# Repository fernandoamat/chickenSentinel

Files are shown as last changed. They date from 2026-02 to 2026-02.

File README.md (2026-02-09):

# ChickenSentinel

An autonomous chicken deterrent system using computer vision and a water spray turret. The system detects birds and other animals using a DepthAI OAK-D stereo camera with YOLOv6 object detection, then tracks and sprays targets that venture outside designated "safe zones" (grass areas).

This project was develop in partnership with Gemini 3.0 to refine the ideas and parts list and then with Claude Code to implement all the code. It is definitely a passion project but it is saving my lawn and patio from being invaded by my chickens.

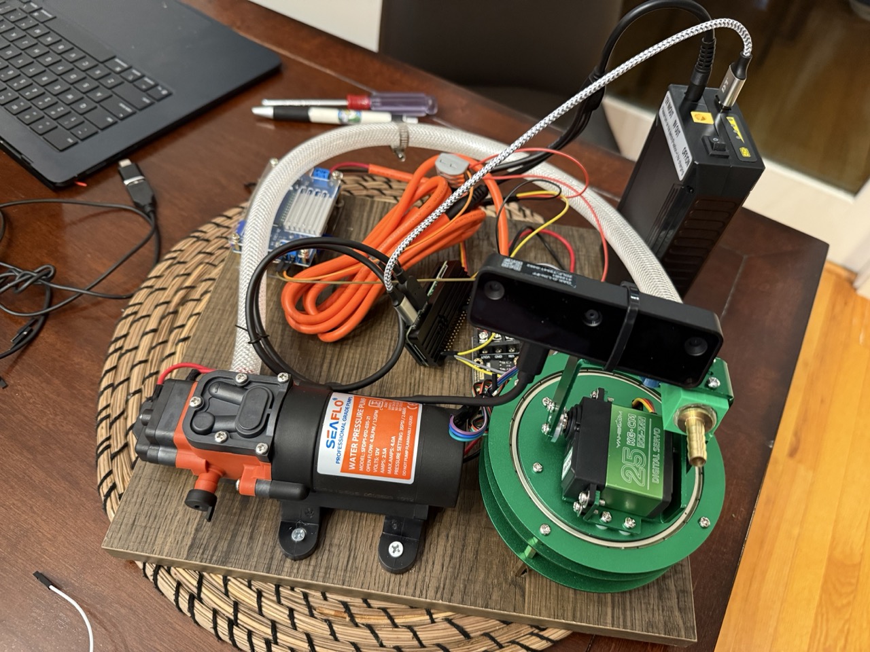
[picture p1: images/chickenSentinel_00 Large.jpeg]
chickenSentinel00
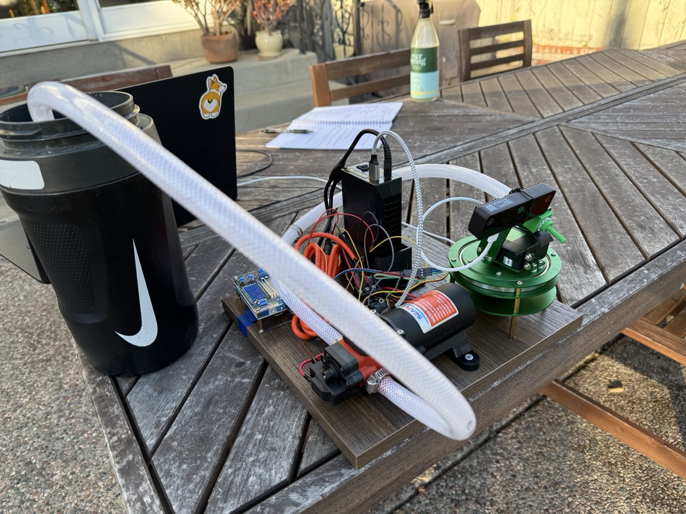
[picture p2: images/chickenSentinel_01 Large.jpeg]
chickenSentinel01

Pictures of how the final system looks like. It is totally portable in a 12x12 wood board. The battery can easily be removed to charge. It last ~6-8 hours as long as it is not shooting all the time. Right image shows final build with the pump connected to bucket with water.

[Video](https://github.com/user-attachments/assets/673e242a-7802-41d2-aea9-533b167c6f6e) demonstrating the system detecting and squirting water to a bottle (capturing footage with the chickens was hard). It much easier to debug with inanimate objects but the system works exactly the same with any other object (like chickens) that can be detected and tracked by the camera.

## System Block Diagram

```
       +-----------------------+
       |   TalentCell Battery  |
       |  (12V DC  &  5V USB)  |
       +---+---------------+---+
           |               |
           | 12V           | 5V USB
           v               v
    +-------------+   +-------------------------+
    |  Water Pump |   |  Raspberry Pi Zero 2 W  |
    |   (12V DC)  |   |      (Controller)       |
    +------+------+   +----+-------+--------+---+
           |               |       |        |
           |               | USB   | GPIO   | GPIO
           |               v       v        v
    +------+------+   +--------+  +----+  +--------+
    |   MOSFET    |<--| GPIO 17|  |Pan/|  | OAK-D  |
    |  (Switch)   |   +--------+  |Tilt|  | Lite   |
    +-------------+               |Svrs|  | Camera |
           ^                      +----+  +--------+
           |
      Common GND
```

## Software design
```
┌─────────────────────┐     USB      ┌─────────────────────────────────┐
│      OAK-D          │─────────────▶│     Raspberry Pi Zero 2W        │
│  Stereo Camera      │              │                                 │
│                     │              │  ┌─────────────────────────┐    │
│  - Color camera     │              │  │  auto_turret_control.py │    │
│  - Left/Right mono  │              │  │                         │    │
│  - VPU (runs YOLO)  │              │  │  State Machine:         │    │
│                     │              │  │  SCANNING → TRACKING    │    │
│  Outputs:           │              │  │  TRACKING → SHOOTING    │    │
│  - Detections       │              │  │  SHOOTING → COOLDOWN    │    │
│  - Spatial coords   │              │  └───────────┬─────────────┘    │
│  - RGB frames       │              │              │                  │
└─────────────────────┘              │              ▼                  │
                                     │  ┌─────────────────────────┐    │
                                     │  │  Hardware Control       │    │
                                     │  │  - Pan servo (GPIO 12)  │    │
                                     │  │  - Tilt servo (GPIO 13) │    │
                                     │  │  - Water pump (GPIO 17) │    │
                                     │  └─────────────────────────┘    │
                                     └─────────────────────────────────┘
```

**Key insight:** YOLO inference runs on the OAK-D's neural accelerator (VPU), not on the Raspberry Pi. The Pi only receives detection results, making this efficient enough for the resource-constrained Zero 2W.

## Hardware Requirements

- **Camera:** OAK-D or OAK-D Lite (DepthAI-compatible stereo camera)
  - Color camera (CAM_A)
  - Left/Right mono cameras (CAM_B, CAM_C) for stereo depth
- **Controller:** Raspberry Pi Zero 2W (or any Pi with GPIO)
- **Actuators:**
  - 2x servo motors (pan/tilt) - standard 50Hz PWM servos
  - Water pump with relay/MOSFET control
- **Power:** Appropriate power supply for servos and pump

### GPIO Pin Assignments

| Component | GPIO Pin | PWM Channel |
|---|---|---|
| Pan Servo | 12 | Channel 0 |
| Tilt Servo | 13 | Channel 1 |
| Water Pump | 17 | Digital Out |

## 🛠️ Parts lists
Total cost in December 2025 for the entire project was around $350.

| Component | Description | Model / Notes | Buy Link |
| :--- | :--- | :--- | :--- |
| **Controller** | Single Board Computer | **Raspberry Pi Zero 2 W**<br>The brain of the sentinel. | [Buy from Raspberry Pi](https://www.raspberrypi.com/products/raspberry-pi-zero-2-w/) |
| **Camera** | AI Camera | **Luxonis OAK-D Lite**<br>Planned upgrade for person/animal detection. | [Buy from Luxonis](https://shop.luxonis.com/products/oak-d-lite-1) |
| **Turret Mechanism** | Pan/Tilt Kit | **Pan/Tilt Bracket + 2x Servos**<br>Generic kit for aiming. | [Amazon](https://www.amazon.com/Yahboom-Pan-Tilt-Electric-Platform-Accessories/dp/B0BRXVFCKX) |
| **Water Cannon** | Pump | **12V DC Submersible Pump**<br>Connected to GPIO 17 via MOSFET. | [Amazon](https://www.amazon.com/dp/B00DLKT4OO) |
| **Pump Control** | Switch | **MOSFET Module DF-DFR0457**<br>Allows the 3.3V Pi to switch on/off the 12V pump. | [Buy from TME](https://www.tme.com/us/en-us/details/df-dfr0457/others-power-supply-modules/dfrobot/dfr0457/) |
| **Power Supply** | Battery | **TalentCell Rechargeable 12V/5V**<br>Powers both the Pi (via 5V USB) and Pump (via 12V DC). | [Amazon](https://www.amazon.com/dp/B01337QXMA) |
| **DC Buck Converter** | Converter | **Adjustable Power Supply**<br>Lowers the DC current of the battery from 12V to 7.6V for the servos. | [Amazon](https://www.amazon.com/dp/B078Q1624B) |
| **Power Splitter** | Cable Splitter | **Y-Splitter Cable**<br>Power splitter for both servos. | [Amazon](https://www.amazon.com/dp/B0FCD32RBB) |
| **USB Power Cable** | Power Cable | **USB to Barrel Jack**<br>Powers Raspberry Pi from battery. | [Amazon](https://www.amazon.com/dp/B0FS651N2G) |
| **DC Power Cables** | Power Cables | **DC Barrel Cables**<br>Connects splitter to DC converter. | [Amazon](https://www.amazon.com/dp/B0CRB1QP71) |
| **Vinyl Tubing** | Water Tubing | **Flexible Vinyl Tube**<br>Carries water from pump to nozzle. | [Amazon](https://www.amazon.com/dp/B07MTYMW13) |
| **USB-C Cable** | Data Cable | **USB-C to USB-A**<br>Connects OAK-D camera to Raspberry Pi. | [Amazon](https://www.amazon.com/dp/B0D97GS238) |
| **Jumper Wires** | Wiring | **Dupont Jumper Wires**<br>Pin wires to connect GPIO components. | [Amazon](https://www.amazon.com/dp/B01EV70C78) |

## File Structure

```
chickenSentinel/
├── chicken_tracker.py          # Desktop visualization with YOLO + depth
├── raspberrypi/
│   ├── auto_turret_control.py  # Autonomous turret controller
│   └── manual_turret_control.py # Manual servo/pump testing
├── notebooks/
│   └── debug_green_mask.ipynb  # Green zone detection debugging
├── openscad/                   # 3D printable parts
│   ├── nozzleAttachmentServo.scad
│   └── batteryBase.scad
├── pyproject.toml              # Project dependencies
├── CLAUDE.md                   # AI assistant instructions
└── README.md                   # This file
```

## Installation

```bash
# Clone the repository
git clone https://github.com/yourusername/chickenSentinel.git
cd chickenSentinel

# Install dependencies (uses uv package manager)
uv sync

# For Raspberry Pi, also install hardware PWM support:
pip install rpi-hardware-pwm gpiozero
```

## Usage

### Automated Turret (Production)

Run on the Raspberry Pi connected to the OAK-D camera:

```bash
uv run python raspberrypi/auto_turret_control.py
```

Monitor via SSH - the script outputs timestamped logs:
```
14:32:15 [INFO] Pipeline started. Entering main loop...
14:32:18 [INFO] Target acquired: bird conf=0.87 z=2450mm
14:32:19 [INFO] Centered! X=32mm. Shooting...
14:32:22 [INFO] Shot complete. Cooldown...
14:32:23 [INFO] Resuming tracking
14:32:26 [INFO] Target lost for 5.0s. Scanning...
14:32:45 [INFO] Status: state=SCANNING, pan=-15.0, tilt=0.0, detections=3
```

### Manual Turret Control (Testing)

For manual testing of servos and pump:

```bash
uv run python raspberrypi/manual_turret_control.py
```

Controls:
- Arrow keys: Pan/Tilt
- `s`: Shoot (3 seconds)
- `q`: Quit

### Desktop Visualization (Development)

For development/debugging with video display:

```bash
uv run python chicken_tracker.py
```

## Auto Turret Control - Detailed Documentation

### State Machine

The turret operates as a finite state machine with 4 states:

```
                    ┌──────────────────────────────────────┐
                    │                                      │
                    ▼                                      │
┌──────────┐   detection    ┌──────────┐   centered    ┌──────────┐
│ SCANNING │──────────────▶│ TRACKING │──────────────▶│ SHOOTING │
└──────────┘               └──────────┘               └──────────┘
     ▲                          │                          │
     │                          │                          │
     │      target lost         │                          │
     │      for 5 seconds       │                          │
     │◀─────────────────────────┤                          │
     │                                                     │
     │                     ┌──────────┐                    │
     │    cooldown done    │ COOLDOWN │◀───────────────────┘
     │◀────────────────────┴──────────┘    shoot done
```

| State | Description | Transitions |
|---|---|---|
| `SCANNING` | No target detected. Pans back and forth within `SCAN_RANGE`. Tilt at neutral (0°). | → TRACKING (when valid target detected) |
| `TRACKING` | Target acquired. Adjusts pan/tilt to center target using trigonometry-based control. | → SHOOTING (when centered), → SCANNING (target lost for 5s) |
| `SHOOTING` | Pump activated. Holds position for `SHOOT_DURATION`. | → COOLDOWN (when done) |
| `COOLDOWN` | Pause after shooting (`COOLDOWN_DURATION`) or after full scan with no targets (`IDLE_COOLDOWN_DURATION`). | → TRACKING (if target visible), → SCANNING (if no target) |

### Configuration Constants

All tunable parameters are at the top of `raspberrypi/auto_turret_control.py`:

#### Detection Settings

| Constant | Default | Description |
|---|---|---|
| `ALLOWED_CLASSES` | `{'bird', 'horse', 'sheep', 'cow', 'bear', 'bottle'}` | YOLO classes to target |
| `FPS` | 15 | Camera frame rate (reduced for efficiency) |

#### Timing

| Constant | Default | Description |
|---|---|---|
| `SHOOT_DURATION` | 3.0 | Seconds to spray water |
| `COOLDOWN_DURATION` | 10.0 | Seconds pause after shooting |
| `IDLE_COOLDOWN_DURATION` | 30.0 | Seconds to idle after full scan with no detections |
| `GREEN_MASK_INTERVAL` | 10.0 | Seconds between green mask updates |

#### Scanning Mode

| Constant | Default | Description |
|---|---|---|
| `SCAN_RANGE` | `(-40, 60)` | Pan angle range in degrees |
| `SCAN_STEP` | 5 | Degrees per scan movement |
| `SCAN_DELAY` | 0.5 | Seconds between scan steps |
| `SCANNING_TILT_ANGLE` | 25.0 | Tilt angle during scanning (degrees) |

#### Tracking Control

| Constant | Default | Description |
|---|---|---|
| `CENTERING_THRESHOLD` | 50 | mm X-offset to consider "centered" |
| `TRACKING_DELAY` | 0.5 | Seconds to wait after servo command before next measurement |
| `TARGET_DETECTION_CONFIDENCE_THRESHOLD` | 0.5 | Minimum confidence to consider a detection valid |
| `TARGET_LOST_TIMEOUT` | 5.0 | Seconds before scanning after losing target |
| `MAX_PAN_RATE` | 2.0 | Maximum degrees per update cycle (smooth movement) |

#### Monitoring

| Constant | Default | Description |
|---|---|---|
| `STATUS_LOG_INTERVAL` | 30.0 | Seconds between periodic status logs |

### Key Functions

#### `calculate_target_y(z_mm: float) -> float`

**Location:** `auto_turret_control.py:102-118`

Calculates the target Y coordinate (in mm) that the turret should aim at based on target distance. The tilt servo uses proportional control to minimize the offset between the detection's actual Y coordinate and this target value. **This needs calibration** based on your turret mounting position and water nozzle trajectory.

Current implementation uses a linear regression formula:
```python
def calculate_target_y(z_mm: float) -> float:
    # y = 0.3654 * z - 282.318
    return (0.3654 * z_mm) - 282.318
```

Both pan and tilt use trigonometry-based angle calculations:
- **Pan**: Uses `atan2(x_offset, z_depth)` to calculate the exact angular offset to center the target horizontally
- **Tilt**: Uses `atan2(y_offset, z_depth)` where y_offset is the difference between actual Y and the calibrated target Y

#### `GreenZoneDetector`

**Location:** `auto_turret_control.py:126-174`

Detects grass/green areas using simple RGB thresholding. Targets standing on grass are considered "safe" and won't be sprayed.

- Updates mask every `GREEN_MASK_INTERVAL` seconds
- A pixel is "green" if: `G > R + threshold` AND `G > B + threshold`

#### `is_valid_spatial_coordinates(detection) -> bool`

**Location:** `auto_turret_control.py:182-199`

Validates that a detection has usable 3D coordinates:
- Checks for NaN values in x, y, z coordinates
- Ensures depth (z) is positive

#### `select_best_detection()`

**Location:** `auto_turret_control.py:202-244`

Selects the highest-confidence detection that:
1. Is in `ALLOWED_CLASSES`
2. Has valid spatial coordinates (not NaN, positive depth)
3. Is within 4000mm depth range
4. During scanning: has Y coordinate above -600mm

### Safety Features

The system will only shoot when ALL conditions are met:
1. Target class is in `ALLOWED_CLASSES`
2. Target has valid spatial coordinates (not NaN, positive depth)
3. Target depth is less than 4000mm
4. Target is centered (X offset < `CENTERING_THRESHOLD`)
5. Not in cooldown period

**Note:** Green zone detection (grass area filtering) is implemented but currently disabled in the code. A physical boundary was found to be more reliable than tuning the green detector.

### Robustness Features

The code includes several robustness improvements for reliable operation:

- **Non-blocking detection queue**: Uses `tryGet()` to prevent hanging if camera disconnects
- **Graceful degradation**: State machine continues running even without camera data
- **Hardware cleanup guarantee**: `finally` block ensures pump/servos are stopped on any exit
- **Exception handling**: All hardware operations wrapped in try/except with logging
- **Periodic status logging**: Logs state, angles, and detection count every 30 seconds
- **Pan rate limiting**: Prevents jerky servo movements with `MAX_PAN_RATE`
- **Tilt reset on scan**: Returns tilt to neutral when entering scanning mode

## Calibration Guide

### 1. Tracking Rate Tuning

The turret uses trigonometry-based angle calculations with `math.atan2()` to determine the exact angular offset to the target. The `MAX_PAN_RATE` constant limits how fast the servos can move per update cycle for smooth tracking.

If tracking is too slow, increase `MAX_PAN_RATE`. If the servos oscillate or overshoot, decrease it.

```python
MAX_PAN_RATE = 2.0  # Maximum degrees per update cycle
```

### 2. Target Y Calibration

The `calculate_target_y()` function defines what Y coordinate (in mm) the turret should aim at for a given depth. To calibrate:

1. Place a target at known distances (e.g., 1m, 2m, 3m, 4m, 5m)
2. For each distance, note the Y coordinate reported when the water hits the target
3. Fit a linear regression to your data points (Z vs Y)
4. Update the formula in `calculate_target_y()`

### 3. Green Zone Threshold

If the green detection is too sensitive (missing grass) or not sensitive enough (detecting non-grass as grass), adjust:

```python
# In GreenZoneDetector.__init__()
self.threshold = 0  # Increase if false positives, decrease if missing grass
```

## Dependencies

- `depthai>=3.2.1` - DepthAI camera SDK
- `opencv-python>=4.11.0.86` - Computer vision
- `numpy>=2.3.5` - Numerical processing
- `blobconverter>=1.4.3` - Neural network model conversion
- `matplotlib>=3.10.8` - Plotting (for debugging notebooks)
- `gpiozero>=2.0.1` - GPIO control (Raspberry Pi)
- `rpi-hardware-pwm` - Hardware PWM for servos (Raspberry Pi)

## 3D Printed Parts

The `openscad/` directory contains STL files for custom mounting hardware. All parts were designed in OpenSCAD and can be modified if needed.

| Part | File | Description |
| :--- | :--- | :--- |
| **Nozzle Adapter** | `nozzleAttachmentServo.stl` | Mounts the brass hose fitting to the pan/tilt bracket. Uses M3 screws. |
| **Battery Holder** | `batteryBase.stl` | Sleeve for the TalentCell battery with screw-down mounting flanges. |
| **Hose Connector** | `M0110_double-ended-barbed-hose-connector.stl` | Barbed connector for vinyl tubing. Can also be purchased online. |

**Print settings:** PLA or PETG, 0.2mm layer height, 20% infill. No supports needed.

## License

MIT License

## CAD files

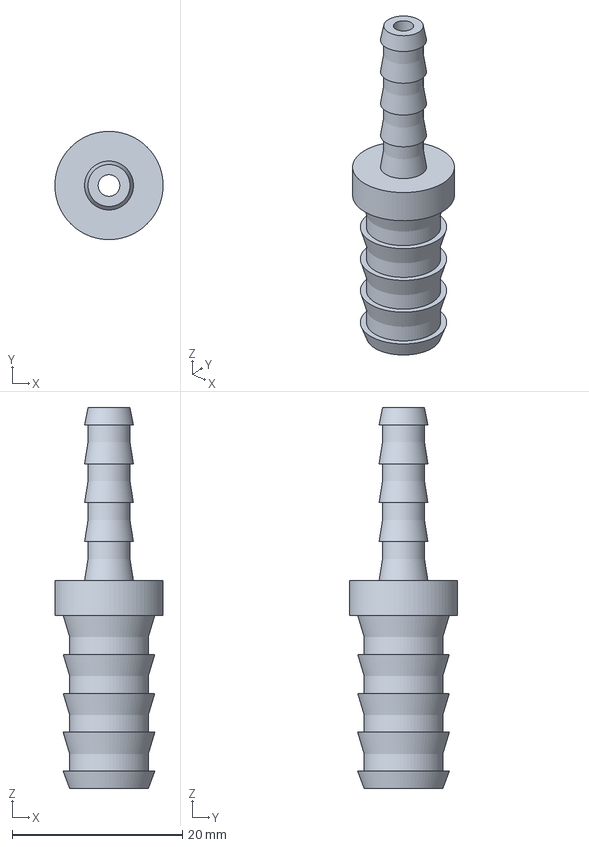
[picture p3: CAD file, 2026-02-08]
openscad/M0110_double-ended-barbed-hose-connector.3mf
12.7 x 12.7 x 44.7 mm

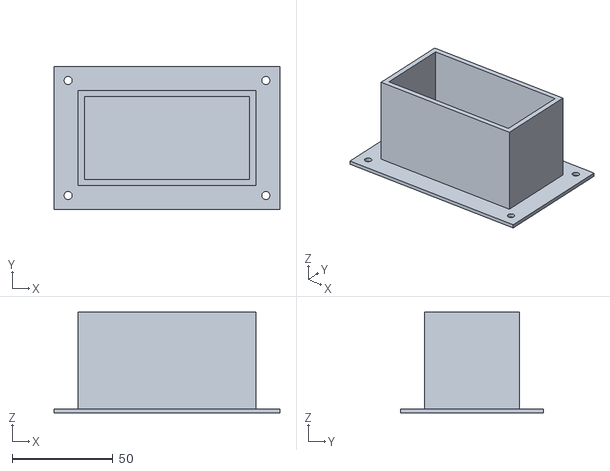
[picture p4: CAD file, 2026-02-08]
openscad/batteryBase.stl
112.0 x 71.0 x 50.0

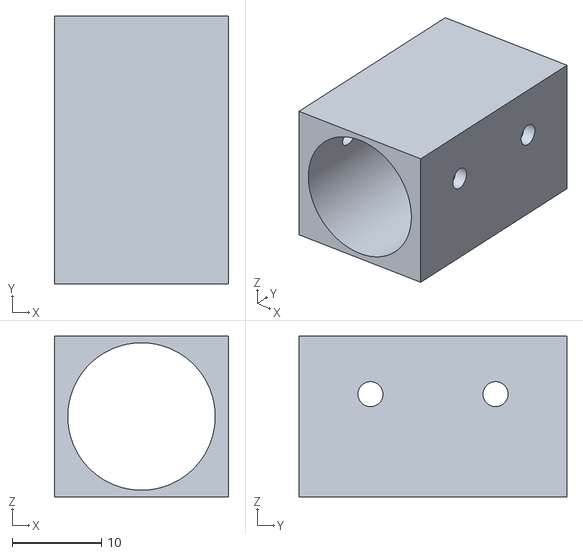
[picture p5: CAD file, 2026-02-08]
openscad/nozzleAttachmentServo.stl
19.5 x 30.0 x 18.0

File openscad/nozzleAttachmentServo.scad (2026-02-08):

// --- MEASURE YOUR BRASS FITTING ---
nozzle_barrel_dia = 16.5;    // Diameter of the round threaded part

// --- MOUNTING SETTINGS ---
// 2.8mm is tight for M3, allowing the screw to cut its own threads into the plastic.
// If it's too hard to screw in, drill it out slightly to 3.0mm.
mount_screw_dia = 2.8;     
hole_spacing = 14;         // Distance between the two mounting holes
whole_offset = 2.5;      // Offset to the wall

$fn=100;

difference() {
    // 1. The Main Block
    cube([nozzle_barrel_dia + 3, 30, nozzle_barrel_dia + 1.5], center=true);


    // 3. The Barrel Exit (Where water comes out)
    rotate([90, 0, 0])
        translate([0, 0, -10])
            cylinder(h=20, d=nozzle_barrel_dia, center=true);
            
    // 4. The Hose Entrance (Rear)
    rotate([90, 0, 0])
        translate([0, 0, 10])
            cylinder(h=30, d=nozzle_barrel_dia, center=true);

    // 5. Fixed Mounting Holes (13mm spacing)
    // Top Hole
    translate([0, hole_spacing/2, whole_offset]) 
        rotate([0, 90, 0]) 
            cylinder(h=30, d=mount_screw_dia, center=true);
            
    // Bottom Hole
    translate([0, -hole_spacing/2, whole_offset]) 
        rotate([0, 90, 0]) 
            cylinder(h=30, d=mount_screw_dia, center=true);
}

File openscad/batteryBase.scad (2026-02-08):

// --- Parameters ---

// Inner dimensions of the sleeve (Battery size + tolerance)
// I have set these to match the standard YB1208300-USB (approx 80mm x 39mm)
inner_width = 82;  // Long side (approx 8cm + clearance)
inner_depth = 41;  // Short side (approx 4cm + clearance)

// Height of the sleeve walls
total_height = 50;

// Thickness of the walls and base floor
wall_thickness = 3;
floor_thickness = 2; 

// Width of the mounting tabs (ears) for the screws
tab_width = 12;

// Screw hole diameter (standard M3 or wood screw is ~3-4mm)
screw_hole_diameter = 4;

// Smoothness of circles
$fn = 60;

// --- Main Render ---

difference() {
    // 1. The main solid body (Base + Walls)
    union() {
        // The Sleeve Walls (Outer Block)
        translate([0, 0, total_height/2])
            cube([inner_width + 2*wall_thickness, inner_depth + 2*wall_thickness, total_height], center=true);
        
        // The Mounting Flanges (Base ears at corners)
        // We create a larger flat plate at the bottom for the screws
        translate([0, 0, floor_thickness/2])
            cube([inner_width + 2*wall_thickness + 2*tab_width, inner_depth + 2*wall_thickness + 2*tab_width, floor_thickness], center=true);
    }

    // 2. Subtract the "Hole" for the battery
    // We shift it up by 'floor_thickness' so the battery sits on a floor, not the wood.
    translate([0, 0, floor_thickness + (total_height/2)])
        cube([inner_width, inner_depth, total_height + 1], center=true);

    // 3. Subtract the Screw Holes (4 Corners)
    // We calculate the positions based on the total size
    
    // X and Y positions for the holes
    hole_x = (inner_width/2) + wall_thickness + (tab_width/2) - 1; 
    hole_y = (inner_depth/2) + wall_thickness + (tab_width/2) - 1;

    // Front-Right
    translate([hole_x, hole_y, -1])
        cylinder(h = total_height + 2, d = screw_hole_diameter);
    
    // Front-Left
    translate([-hole_x, hole_y, -1])
        cylinder(h = total_height + 2, d = screw_hole_diameter);
        
    // Back-Right
    translate([hole_x, -hole_y, -1])
        cylinder(h = total_height + 2, d = screw_hole_diameter);
        
    // Back-Left
    translate([-hole_x, -hole_y, -1])
        cylinder(h = total_height + 2, d = screw_hole_diameter);
}

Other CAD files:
openscad/M0110_double-ended-barbed-hose-connector.stl

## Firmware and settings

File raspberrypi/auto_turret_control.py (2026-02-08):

"""
Automated turret control for Raspberry Pi Zero 2W.

Combines DepthAI YOLOv6 detection with servo control for autonomous
chicken deterrent. YOLO inference runs on OAK-D's VPU (neural accelerator),
so the RPi only handles lightweight control logic.

Usage:
    uv run python raspberrypi/auto_turret_control.py
"""

import logging
import math
import time
from enum import Enum

import depthai as dai
import numpy as np
from gpiozero import DigitalOutputDevice
from rpi_hardware_pwm import HardwarePWM

# =============================================================================
# CONFIGURATION - Adjust these constants as needed
# =============================================================================

# Detection settings
ALLOWED_CLASSES = {'bird', 'horse', 'sheep', 'cow', 'bear', 'bottle'}
FPS = 15  # Reduced from 30 for RPi Zero 2W efficiency

# Timing
SHOOT_DURATION = 3.0  # Seconds to spray water
COOLDOWN_DURATION = 10.0  # Seconds after shooting before resuming
IDLE_COOLDOWN_DURATION = 30.0  # Seconds to idle after full scan with no detections. Increase to preserve battery.
GREEN_MASK_INTERVAL = 10.0  # Seconds between green mask updates. Increase to reduce CPU load.

# Scanning mode
SCAN_RANGE = (-40, 60)  # Pan angle range (degrees)
SCAN_STEP = 5  # Degrees per scan movement
SCAN_DELAY = 0.5  # Seconds between scan steps
SCANNING_TILT_ANGLE = 25.0  # Tilt angle during scanning (degrees). Adjust to your mounting position.

# Tracking control
CENTERING_THRESHOLD = 50  # mm - X offset considered "centered"
TRACKING_DELAY = 0.5  # Seconds to wait after servo command before next measurement

# Targeting control
TARGET_DETECTION_CONFIDENCE_THRESHOLD = 0.5  # Minimum confidence to consider a detection valid. Increase to reduce false positives.

# Hardware pins
PUMP_PIN = 17
PAN_PWM_CHANNEL = 0  # GPIO 12
TILT_PWM_CHANNEL = 1  # GPIO 13

# Tracking behavior
TARGET_LOST_TIMEOUT = 5.0  # Seconds before scanning after losing target
MAX_PAN_RATE = 2.0  # Maximum degrees per update cycle for smooth movement. Critical for smooth tracking.

# Monitoring
STATUS_LOG_INTERVAL = 30.0  # Seconds between periodic status logs

# =============================================================================
# HARDWARE SETUP
# =============================================================================


def set_angle(pwm_device, angle: float, log) -> None:
    """
    Set servo angle.

    Args:
        pwm_device: HardwarePWM instance
        angle: Angle in degrees (-90 to +90)
    """
    # too much logging
    # log.info(f"Setting servo angle (pan or tilt) to {angle} degrees")
    angle = max(-90, min(90, angle))
    # Convert angle to duty cycle (Equation: 2.5 + (angle + 90) / 180 * 10)
    # Servo PWM: 2.5% = -90deg, 7.5% = 0deg, 12.5% = +90deg
    duty_cycle = 2.5 + (angle + 90) / 18.0
    pwm_device.change_duty_cycle(duty_cycle)


# =============================================================================
# STATE MACHINE
# =============================================================================


class TurretState(Enum):
    SCANNING = 1  # No detection, panning to search
    TRACKING = 2  # Detection found, centering on target
    SHOOTING = 3  # Centered and outside green zone, firing
    COOLDOWN = 4  # Just shot, brief pause before next action


# =============================================================================
# TARGET Y CALCULATION
# You need to change this method based on your own calibration data
# It depends on where you mount the turret
# =============================================================================


def calculate_target_y(z_mm: float) -> float:
    """
    Calculate target Y coordinate (mm) based on target distance (Z).

    The turret should aim to minimize the offset between the detection's
    actual Y coordinate and this target Y value.

    Args:
        z_mm: Distance to target in millimeters

    Returns:
        Target Y coordinate in millimeters

    """
    # Linear regression formula: y = 0.3654 * z - 282.318
    # You need to change this based on your own calibration data
    return (0.3654 * z_mm) - 282.318


# =============================================================================
# GREEN ZONE DETECTION
# =============================================================================


class GreenZoneDetector:
    """
    Detects green zones (grass) in camera frames.

    Animals in green zones are considered safe and won't be targeted.
    Uses simple RGB threshold: a pixel is "green" if G > R and G > B.
    """

    def __init__(self, threshold: int = 0, update_interval: float = GREEN_MASK_INTERVAL):
        self.threshold = threshold
        self.update_interval = update_interval
        self.last_mask = None
        self.last_update = 0.0

    def update_mask(self, rgb_frame: np.ndarray) -> None:
        """Update green mask if interval has elapsed."""
        now = time.time()
        if self.last_mask is None or (now - self.last_update) >= self.update_interval:
            # Green channel must exceed both R and B by threshold
            g = rgb_frame[:, :, 1].astype(np.int16)
            self.last_mask = (
                ((g - rgb_frame[:, :, 2]) > self.threshold) &
                ((g - rgb_frame[:, :, 0]) > self.threshold)
            )
            self.last_update = now

    def is_outside_green(self, detection) -> bool:
        """
        Check if detection centroid is outside the green zone.

        Args:
            detection: Detection object with xmin, xmax, ymin, ymax (normalized 0-1)

        Returns:
            True if centroid is on a non-green pixel, False otherwise.
        """
        if self.last_mask is None:
            return False

        h, w = self.last_mask.shape
        cx = int(((detection.xmin + detection.xmax) / 2) * w)
        cy = int(((detection.ymin + detection.ymax) / 2) * h)

        # Clamp to valid coordinates
        cx = max(0, min(cx, w - 1))
        cy = max(0, min(cy, h - 1))

        # Outside green = mask is False at that pixel
        return not self.last_mask[cy, cx]


# =============================================================================
# DETECTION SELECTION
# =============================================================================


def is_valid_spatial_coordinates(detection) -> bool:
    """
    Check if detection has valid spatial coordinates.

    Args:
        detection: Detection object with spatialCoordinates

    Returns:
        True if coordinates are valid (non-zero depth, not NaN).
    """
    coords = detection.spatialCoordinates
    # Check for NaN
    if coords.x != coords.x or coords.y != coords.y or coords.z != coords.z:
        return False
    # Check for zero/invalid depth
    if coords.z <= 0:
        return False
    return True


def select_best_detection(detections, allowed_classes: set,
                          green_detector: GreenZoneDetector, log, is_scanning: bool = False):
    """
    Select the highest-confidence detection from allowed classes outside green zone.

    Args:
        detections: List of detection objects
        allowed_classes: Set of class names to consider
        green_detector: GreenZoneDetector instance
        is_scanning: If True, apply stricter y_nm filtering

    Returns:
        Best detection or None if no valid detection found.
    """
    valid = []
    for det in detections:
        #log.info(f"Select best detection: processing {det.labelName}")
        if det.labelName not in allowed_classes:
            continue
        #log.info("Before is_valid_spatial_coordinates")
        if not is_valid_spatial_coordinates(det):
            continue
        # Filter by depth and height boundaries
        # The target must be within reasonable distance (z_nm low)
        # The target has to be on the lower part of the frame (y_nm high). So even when shooting that will be the case
        z_nm = det.spatialCoordinates.z
        y_nm = det.spatialCoordinates.y
        if z_nm >= 4000:
            continue
        elif is_scanning and y_nm <= -600:
            continue
        #log.info("Before green_detector")
        # it was easier to setup a physical boundary than to tune the green detector
        #if not green_detector.is_outside_green(det):
        #    continue
        log.info(f"Adding {det.labelName} to valid detections. Coordinates: x={det.spatialCoordinates.x:.2f}, y={det.spatialCoordinates.y:.2f}, z={det.spatialCoordinates.z:.2f} Passed all checks")
        valid.append(det)

    if not valid:
        return None

    # Return detection with highest confidence
    return max(valid, key=lambda d: d.confidence)


# =============================================================================
# MAIN CONTROL LOOP
# =============================================================================


def main():
    # Setup logging
    logging.basicConfig(
        level=logging.INFO,
        format='%(asctime)s [%(levelname)s] %(message)s',
        datefmt='%H:%M:%S'
    )
    log = logging.getLogger('turret')

    # Initialize hardware (done here, not at module level, for better error handling)
    log.info("Initializing hardware...")
    try:
        pan_servo = HardwarePWM(pwm_channel=PAN_PWM_CHANNEL, hz=50)
        tilt_servo = HardwarePWM(pwm_channel=TILT_PWM_CHANNEL, hz=50)
        pump = DigitalOutputDevice(PUMP_PIN)
    except Exception as e:
        log.error(f"Failed to initialize hardware: {e}")
        log.error("Make sure you're running on a Raspberry Pi with proper GPIO access.")
        return

    try:
        pan_servo.start(0)
        tilt_servo.start(0)
    except Exception as e:
        log.error(f"Failed to start servos: {e}")
        return

    # State variables
    state = TurretState.SCANNING
    pan_angle = 0.0
    tilt_angle = SCANNING_TILT_ANGLE  # start upright
    last_target_seen_time = time.time()  # Tracks when we last saw a target (for faster scan resumption)
    scan_direction = 1  # 1 = moving toward positive, -1 = toward negative
    shoot_start = 0.0
    cooldown_start = 0.0
    last_status_log = time.time()  # For periodic status logging
    detection_count = 0  # Count valid detections for status logging
    scan_detected_target = False  # Track if target seen during current scan sweep
    is_idle_cooldown = False  # Distinguish idle vs post-shoot cooldown

    green_detector = GreenZoneDetector()

    log.info("Initializing DepthAI pipeline...")

    # Wrap everything in try/finally to ensure hardware cleanup even if pipeline setup fails
    try:
        # Build DepthAI pipeline
        with dai.Pipeline() as p:
            # Camera setup
            camRgb = p.create(dai.node.Camera).build(dai.CameraBoardSocket.CAM_A)
            monoLeft = p.create(dai.node.Camera).build(dai.CameraBoardSocket.CAM_B)
            monoRight = p.create(dai.node.Camera).build(dai.CameraBoardSocket.CAM_C)
            stereo = p.create(dai.node.StereoDepth)

            # Spatial detection network (YOLO runs on OAK-D VPU)
            modelDesc = dai.NNModelDescription("yolov6-nano")
            spatialNet = p.create(dai.node.SpatialDetectionNetwork).build(
                camRgb, stereo, modelDesc, fps=FPS
            )

            # Configure stereo depth
            stereo.setExtendedDisparity(True)
            platform = p.getDefaultDevice().getPlatform()
            if platform == dai.Platform.RVC2:
                stereo.setOutputSize(640, 400)

            # Configure spatial detection network
            spatialNet.input.setBlocking(False)
            spatialNet.setBoundingBoxScaleFactor(0.5)
            spatialNet.setDepthLowerThreshold(100)
            spatialNet.setDepthUpperThreshold(10000)
            spatialNet.setConfidenceThreshold(TARGET_DETECTION_CONFIDENCE_THRESHOLD)

            # Link mono cameras to stereo
            monoLeft.requestOutput((640, 400)).link(stereo.left)
            monoRight.requestOutput((640, 400)).link(stereo.right)

            # Create output queues (no display needed - headless operation)
            detQueue = spatialNet.out.createOutputQueue()
            rgbQueue = spatialNet.passthrough.createOutputQueue(maxSize=1, blocking=False)

            p.start()
            log.info("Pipeline started. Entering main loop...")

            # Set initial servo positions
            try:
                set_angle(pan_servo, pan_angle, log)
                set_angle(tilt_servo, tilt_angle, log)
            except Exception as e:
                log.error(f"Failed to set initial servo positions: {e}")

            while p.isRunning():
                now = time.time()

                # Periodic status logging for monitoring (always runs)
                if now - last_status_log >= STATUS_LOG_INTERVAL:
                    log.info(
                        f"Status: state={state.name}, pan={pan_angle:.1f}, "
                        f"tilt={tilt_angle:.1f}, detections={detection_count}"
                    )
                    last_status_log = now
                    detection_count = 0

                # Get detections (non-blocking to prevent hanging if camera disconnects)
                det_msg = detQueue.tryGet()

                # Get RGB frame for green mask (non-blocking)
                rgb_msg = rgbQueue.tryGet()
                if rgb_msg is not None:
                    green_detector.update_mask(rgb_msg.getCvFrame())

                # Find best target (only if we have detections)
                target = None
                if det_msg is not None:
                    detections = det_msg.detections
                    target = select_best_detection(
                        detections, ALLOWED_CLASSES, green_detector, log,
                        is_scanning=(state == TurretState.SCANNING)
                    )
                # uncommenting this generates too much log info
                #else:
                #    log.info("Debugging:det_msg is none")

                if target is not None:
                    last_target_seen_time = now
                    detection_count += 1
                    scan_detected_target = True
                    x_offset = target.spatialCoordinates.x  # mm from center
                    z_depth = target.spatialCoordinates.z

                    # Transition from scanning to tracking
                    if state == TurretState.SCANNING:
                        state = TurretState.TRACKING
                        log.info(
                            f"Target acquired: {target.labelName} "
                            f"conf={target.confidence:.2f} z={z_depth:.2f}mm x={x_offset:.2f}mm from center"
                        )

                    if state == TurretState.TRACKING:
                        # Calculate angle to target using trigonometry (not mm-based gain)
                        # This gives the actual angular offset from camera center
                        # NOTE: Pan direction sign may need to be flipped depending on
                        # how your camera and servo are mounted. Test and adjust if needed.
                        angle_to_target = math.degrees(math.atan2(x_offset, z_depth))
                        pan_adjustment = -angle_to_target

                        # Rate limiting: clamp adjustment to MAX_PAN_RATE per cycle
                        pan_adjustment = max(-MAX_PAN_RATE, min(MAX_PAN_RATE, pan_adjustment))
                        pan_angle = max(-90, min(90, pan_angle + pan_adjustment))

                        # Calculate tilt angle using trigonometry (same approach as pan)
                        # Calculate Y offset from target position
                        y_actual = target.spatialCoordinates.y
                        y_target = calculate_target_y(z_depth)
                        y_offset = y_actual - y_target

                        angle_to_target_y = math.degrees(math.atan2(y_offset, z_depth))
                        tilt_adjustment = -angle_to_target_y
                        tilt_adjustment = max(-MAX_PAN_RATE, min(MAX_PAN_RATE, tilt_adjustment))
                        tilt_angle = max(-90, min(90, tilt_angle + tilt_adjustment))

                        try:
                            log.info(
                                f"Tracking: "
                                f"x_offset={x_offset:.1f}mm, angle_x={angle_to_target:.2f}deg, "
                                f"pan_adj={pan_adjustment:.2f}, pan={pan_angle:.2f}; "
                                f"y_offset={y_offset:.1f}mm, angle_y={angle_to_target_y:.2f}deg, "
                                f"tilt_adj={tilt_adjustment:.2f}, tilt={tilt_angle:.2f}"
                            )
                            set_angle(pan_servo, pan_angle, log)
                            set_angle(tilt_servo, tilt_angle, log)
                            # Wait for servo to physically move before next measurement
                            # We are tracking slow moving animals, so this delay is acceptable and adds stability
                            time.sleep(TRACKING_DELAY)
                        except Exception as e:
                            log.error(f"Servo error: {e}")

                        # Check if centered enough to shoot
                        if abs(x_offset) < CENTERING_THRESHOLD:
                            log.info(f"Centered! X={x_offset:.0f}mm. Shooting...")
                            state = TurretState.SHOOTING
                            try:
                                pump.on()
                            except Exception as e:
                                log.error(f"Pump error: {e}")
                            shoot_start = now

                    elif state == TurretState.SHOOTING:
                        # Hold position, wait for shoot duration
                        if now - shoot_start >= SHOOT_DURATION:
                            try:
                                log.info("Debugging: Deactivating pump...")
                                pump.off()
                            except Exception as e:
                                log.error(f"Pump error: {e}")
                            log.info("Shot complete. Cooldown...")
                            state = TurretState.COOLDOWN
                            cooldown_start = now
                            is_idle_cooldown = False

                    elif state == TurretState.COOLDOWN:
                        cooldown_duration = IDLE_COOLDOWN_DURATION if is_idle_cooldown else COOLDOWN_DURATION
                        if now - cooldown_start >= cooldown_duration:
                            state = TurretState.TRACKING
                            log.info("Resuming tracking")

                else:
                    # No valid detection
                    previous_state = state

                    if state == TurretState.SHOOTING:
                        # Finish shooting even if target lost
                        if now - shoot_start >= SHOOT_DURATION:
                            try:
                                pump.off()
                            except Exception as e:
                                log.error(f"Pump error: {e}")
                            log.info("Shot complete (target lost). Scanning...")
                            state = TurretState.SCANNING

                    elif state == TurretState.COOLDOWN:
                        cooldown_duration = IDLE_COOLDOWN_DURATION if is_idle_cooldown else COOLDOWN_DURATION
                        if now - cooldown_start >= cooldown_duration:
                            log.info("Cooldown complete. Scanning...")
                            state = TurretState.SCANNING

                    elif state == TurretState.TRACKING:
                        # Target lost while tracking - use shorter timeout for faster response
                        if now - last_target_seen_time > TARGET_LOST_TIMEOUT:
                            log.info(f"Target lost for {TARGET_LOST_TIMEOUT}s. Scanning...")
                            state = TurretState.SCANNING

                    # Reset tilt to neutral when transitioning to SCANNING
                    if state == TurretState.SCANNING and previous_state != TurretState.SCANNING:
                        tilt_angle = SCANNING_TILT_ANGLE
                        try:
                            set_angle(tilt_servo, tilt_angle, log)
                        except Exception as e:
                            log.error(f"Servo error resetting tilt: {e}")

                    # Execute scanning behavior when in SCANNING state
                    if state == TurretState.SCANNING:
                        # Scan: pan back and forth
                        pan_angle += scan_direction * SCAN_STEP
                        if pan_angle >= SCAN_RANGE[1]:
                            pan_angle = SCAN_RANGE[1]
                            scan_direction = -1
                            if not scan_detected_target:
                                state = TurretState.COOLDOWN
                                cooldown_start = now
                                is_idle_cooldown = True
                                log.info("Full scan complete, no targets. Entering idle cooldown...")
                            scan_detected_target = False
                        elif pan_angle <= SCAN_RANGE[0]:
                            pan_angle = SCAN_RANGE[0]
                            scan_direction = 1
                            if not scan_detected_target:
                                state = TurretState.COOLDOWN
                                cooldown_start = now
                                is_idle_cooldown = True
                                log.info("Full scan complete, no targets. Entering idle cooldown...")
                            scan_detected_target = False
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

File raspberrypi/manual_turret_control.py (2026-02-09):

import curses
from rpi_hardware_pwm import HardwarePWM
from gpiozero import DigitalOutputDevice
from time import sleep

"""
Python script that I can execute in the Raspberry PI where I control the servos 
with the arrow keys (I will be SSHing into the Raspberry Pi to run the Python script) 
and activate the water pump (i.e. "shoot" for 3 seconds) when pressing 
the letter s in my laptop keyboard.

This is great to test the hardware and make sure everything is working.
Also to calibrate the angles of the servos and make sure they are moving in the correct direction.
"""

# --- HARDWARE CONFIGURATION ---
# PWM Channel 0 is usually GPIO 12 or 18
# PWM Channel 1 is usually GPIO 13 or 19
PUMP_PIN = 17
pan_servo = HardwarePWM(pwm_channel=0, hz=50) # GPIO 12
tilt_servo = HardwarePWM(pwm_channel=1, hz=50) # GPIO 13
pump = DigitalOutputDevice(PUMP_PIN)

# Start PWM
pan_servo.start(0)
tilt_servo.start(0)

# --- MAP ANGLES TO DUTY CYCLE ---
# Most servos: 2.5% = -90deg, 7.5% = 0deg, 12.5% = +90deg
def set_angle(pwm_device, angle):
    # Clamp angle between -90 and 90
    angle = max(min(90, angle), -90)
    
    # Convert angle to duty cycle (Equation: 2.5 + (angle + 90) / 180 * 10)
    duty_cycle = 2.5 + (angle + 90) / 18.0
    pwm_device.change_duty_cycle(duty_cycle)

pan_angle = 0
tilt_angle = 45 # start upright
STEP = 5

def main(stdscr):
    global pan_angle, tilt_angle
    
    curses.curs_set(0)
    stdscr.nodelay(True)
    stdscr.clear()
    
    stdscr.addstr(0, 0, "--- CHICKEN SENTINEL (HARDWARE PWM) ---")
    
    # Initialize position
    set_angle(pan_servo, pan_angle)
    set_angle(tilt_servo, tilt_angle)

    while True:
        stdscr.addstr(5, 0, f"Pan: {pan_angle:>3}   Tilt: {tilt_angle:>3}")
        stdscr.refresh()

        try:
            key = stdscr.getch()
        except:
            key = -1

        if key != -1:
            if key == curses.KEY_RIGHT:
                pan_angle -= STEP
            elif key == curses.KEY_LEFT:
                pan_angle += STEP
            elif key == curses.KEY_UP:
                tilt_angle += STEP
            elif key == curses.KEY_DOWN:
                tilt_angle -= STEP
            elif key == ord('s'):
                pump.on()
                sleep(3)
                pump.off()
            elif key == ord('q'):
                break

            set_angle(pan_servo, pan_angle)
            set_angle(tilt_servo, tilt_angle)
            
        sleep(0.05)

    # Cleanup
    pan_servo.stop()
    tilt_servo.stop()

curses.wrapper(main)

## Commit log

2026-02-08 Added openSCAD files for 3D printer designs
    [batteryBase.scad, batteryBase.stl, nozzleAttachmentServo.scad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]
2026-02-08 Added raspberry code. Added nozzle stl 3D printer file
    [M0110_double-ended-barbed-hose-connector.3mf, M0110_double-ended-barbed-hose-connector.stl]
2026-02-08 Fix auto_turret_control to use Y-offset instead of direct depth to tilt adjustment
    [auto_turret_control.py, manual_turret_control.py]
2026-02-08 Modify max depth to detect objects and simplify valid detection logic: anything close to the camera it shoots
